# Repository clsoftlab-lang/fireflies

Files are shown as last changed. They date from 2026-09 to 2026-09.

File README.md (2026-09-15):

# Fireflies (반딧불이)

**English** · [한국어](README.ko.md)

> ### *A sky full of drifting light.*
> Hundreds of tiny helium **sky-jellyfish** — glowing bells with swaying tendrils — let go into
> the dusk air, blinking together in slow, self-organising rhythm, like jellyfish adrift in a
> night sea. Gentle art. Safe. Leave no trace.

Fireflies is an open-source night-sky art project. We release a cloud of thumbnail-size,
self-lit floaters and then **let the wind carry them**. There is no GPS, no steering, no
formation. Each unit only floats and blinks. The drifting *is* the art.

**Project lead:** CLSOFTLAB (씨엘소프트랩), Dr. Lee Il-guk (이일국 박사)
**Contributors:** LWJ (high-school student, Gyeonggi-do), LMJ (middle-school student, Gyeonggi-do),
and Claude (Anthropic's AI). Designed with Claude; **this is not an Anthropic product.**

> [!IMPORTANT]
> **The simulator is the show you can run today.** Open [`sim/`](sim/) in any browser and watch
> thousands of light-jellyfish drift and fall into sync — no hardware, no build step. The
> physical units are an honest reference design; real balloons that lift electronics are bigger
> than the 2 cm dream, and free flight needs permits. See **[Safety & airspace](#safety--airspace)**
> before any real flight.

---

## The one idea: we don't steer them, the wind does

This project began at a riverside at dusk. Clouds of tiny insects drift and swirl on the air,
and real fireflies blink in a rhythm that slowly falls into unison. Fireflies recreates that
feeling with light.

A single button *starts* the show — it releases the units and lights them. After that, **the wind
does the choreography** (principle F1 in the [design spec](docs/en/00-design-spec.md)). No position
holding, no collision avoidance, no drawing letters in the sky. This is the opposite of a
commercial drone light show, and it is what makes Fireflies simple, cheap, and small enough to be
genuinely thumbnail-sized. Drifting apart is not a failure — it is the whole point.

## Two forms: sky-jellyfish and firefly

The same floating, wind-drifting, self-blinking unit comes in two visual forms:

- **Sky-jellyfish (해파리) — the v1 form.** The helium balloon is the *bell*; from it hang 3–8
  feather-light **tendrils**, each carrying a line of micro-LEDs. In the air the tendrils sway and
  trail on the wind exactly like a jellyfish drifting on a current. The light runs **down each
  tendril, top to bottom, in a slow wave**, so the whole thing looks like it is gently pulsing and
  swimming.
- **Firefly — the simpler variant.** A single point of light that blinks: scattered sparks over a
  river.

The [simulator](sim/) draws both.

## How they blink together (no leader)

Each unit carries a tiny internal clock. Its "phase" ramps up smoothly and, when it reaches the top,
the unit flashes and resets. Whenever a unit *sees* a bright neighbour flash — with a little light
sensor — it nudges its own phase forward a touch. That is the only rule, and nobody is in charge.
Yet across a whole drifting swarm, random blinking slowly pulls itself into waves of unison. This is
a **pulse-coupled oscillator** (the Mirollo–Strogatz model), the same trick real fireflies use, and
light is the only channel — no radio, no coordinator. The [simulator](sim/) runs the identical model,
so what you watch on screen is what the hardware aims for.
[Read the friendly, illustrated-in-words explanation →](docs/en/05-synchrony-explained.md)

## A spark-like flash — with no spark

A steady micro-LED is too dim to see at dusk, which is exactly when a firefly show is magical. We
want the sharp, bright *pop* of an electric spark — so each unit makes a **capacitor-boosted LED
flash**: a small capacitor charges quietly, then dumps into the LED for a brief, intense burst, like
a camera flash. It is dark between flashes and snaps bright at the peak, staying visible far across a
dusk sky, and a touch of cool white/blue mixed into the amber can even mimic a spark's colour.

**We never put a real spark or any ignition source on a flying unit.** A free-drifting object can
land anywhere — dry grass, a rooftop, a crowd — and a spark is a fire risk (it is also a one-shot
click, not the gentle repeating blink of a firefly). The capacitor flash gives the crisp spark-like
look with no flame and no ignition, light enough for a micro-balloon. See
[design spec §5.1](docs/en/00-design-spec.md#51-brightness--a-spark-like-flash-without-a-spark).

## Try it now

The simulator **is** the landing experience — the full-scale dream, shareable by a link.

- **In this repo:** open [`sim/index.html`](sim/index.html) in any modern browser (no install, no build).
- **On the web:** <https://clsoftlab-lang.github.io/fireflies/sim/> *(published from `sim/` via GitHub Pages)*.

Play with the number of units, wind strength, blink period, coupling strength and colour, and watch
random flashes drift into slow unison.

## Repository map

```
docs/en, docs/ko   design spec, build guide, safety, leave-no-trace, synchrony
sim/               browser simulator (HTML/CSS/JS, no build) + tests  ← start here
hardware/          firefly/jellyfish unit + dispenser: OpenSCAD parts, BOM, wiring
firmware/          blink + sync firmware (unit) and dispenser controller
site/              optional project page (the simulator is the real landing page)
```

The [design spec](docs/en/00-design-spec.md) is the single source of truth. The `sim/`, `hardware/`
and `firmware/` folders are built by parallel work from that spec; if a folder is not populated in
your checkout yet, the simulator and docs still stand on their own.

## Build it

Order of work — try the simulator first, then build up:

1. **Run the [simulator](sim/)** to understand the drift-and-sync behaviour.
2. **Build one jellyfish (or firefly) unit:** a metallised-film or biodegradable-latex micro-balloon
   *(bell)*, a micro-LED with a capacitor-boosted flash, the smallest coin/film cell that stays
   inside the lift budget, a tiny ATtiny-class blink circuit, and an optional phototransistor for
   sync. For the jellyfish form, add 3–8 feather-light LED tendrils.
3. **Build the dispenser** — one 3D-printable desktop machine that fills a balloon with helium,
   **trims it to near-neutral buoyancy** on a tiny load cell, arms and light-tests the LED, and
   releases units one at a time on a start button (which is also an all-stop).
4. **Run an indoor / tethered show** — the default, legal-anywhere mode.

Full steps and commands: **[Build guide](docs/en/01-build-guide.md)** ·
parts and prices: **[Bill of materials](docs/en/02-bill-of-materials.md)** ([bom.csv](docs/bom.csv)).

> [!NOTE]
> **Honest about size.** A true 2 cm thumbnail unit that carries a micro-LED, a cell and a circuit
> *and* still floats does not exist with today's off-the-shelf parts. The **2 cm unit is
> simulator-only**; the reference *hardware* unit is the smallest we can actually build.
> **The buoyancy one-liner:** helium gives roughly **1 gram of lift per litre** it displaces
> (lift ≈ (air − helium density) × volume × *g*), so a 2 cm balloon (~4 mL) lifts only a few
> milligrams — far less than any real LED and cell. Bigger bell, more lift; trim it until it hangs.

## Safety & airspace

> [!WARNING]
> **Read [Safety & airspace](docs/en/03-safety-and-airspace.md) before any real flight.**
>
> - **Default mode is indoor or tethered** — each unit on a fine, retrievable line. This is the
>   fully-legal-anywhere way to run a show, and it is what the whole reference design is built around.
> - **Free wind-release is advanced and permit-required.** Free-floating lit objects are a hazard
>   to aircraft and are restricted in most countries. In Korea the **Aviation Safety Act**
>   (항공안전법) governs light shows, balloon releases and airborne devices — permission and
>   coordinates are required. Only open, low-altitude, permitted sites, coordinated with local
>   aviation authorities.
> - **Never fly near aircraft or airports, over crowds or roads, or in wildlife-sensitive areas**
>   without review.
> - **Helium is an asphyxiant** in enclosed spaces and cylinders are high-pressure — handle per the
>   hardware guide. Use the smallest safe battery; never release a damaged cell.

## Leave no trace

> [!IMPORTANT]
> **Read [Leave no trace](docs/en/04-leave-no-trace.md).** A firefly is not litter.
>
> - Prefer **tethered + recovered** operation, where nothing is lost.
> - Any free-release uses a **biodegradable envelope**, a **cellulose/paper LED carrier** and a
>   **recoverable or compostable** power source where possible.
> - **Released count must equal recovered/accounted count.** Log every unit and organise collection.
> - There is **no "release thousands and walk away" mode**, and there never will be.

## Contributors

- **Dr. Lee Il-guk (이일국 박사), CLSOFTLAB (씨엘소프트랩)** — project lead and design.
- **LWJ** — contributor (high-school student, Gyeonggi-do).
- **LMJ** — contributor (middle-school student, Gyeonggi-do).
- **Claude (Anthropic's AI)** — design collaborator.

New contributors are very welcome, **especially students and young makers.** See
[CONTRIBUTING.md](CONTRIBUTING.md) and the [Code of Conduct](CODE_OF_CONDUCT.md).

## Sister projects

- [Open Walking Safety Helmet](https://github.com/clsoftlab-lang/open-walking-safety-helmet)
- [RoboSoul humanoid](https://github.com/clsoftlab-lang/robosoul-humanoid)

## Licences

Open licences only:

- **Software** (`sim/`, `firmware/`, scripts, CI): Apache-2.0 — [`LICENSES/Apache-2.0.txt`](LICENSES/Apache-2.0.txt)
- **Hardware** (`hardware/`: OpenSCAD, STL, wiring): CERN-OHL-P-2.0 — [`LICENSES/CERN-OHL-P-2.0.txt`](LICENSES/CERN-OHL-P-2.0.txt)
- **Documentation** (`docs/`, READMEs, images): CC BY 4.0 — [`LICENSES/CC-BY-4.0.txt`](LICENSES/CC-BY-4.0.txt)

See [`NOTICE`](NOTICE) for which licence applies where, and [`LICENSE`](LICENSE) for the full text.

## Not an Anthropic product

Fireflies was designed with Claude, Anthropic's AI assistant. It is an independent open-source
project by CLSOFTLAB. It is **not** an Anthropic product and is not endorsed by Anthropic; there is
no affiliation, and no Anthropic or Claude branding is used.

## Why

Because a riverside at dusk, with the air full of small drifting lights blinking slowly into one
rhythm, is one of the quietest, most beautiful things there is — and everyone should be able to make
one, safely, and leave the river exactly as they found it.

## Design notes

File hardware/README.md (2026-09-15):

<!--
SPDX-License-Identifier: CERN-OHL-P-2.0
SPDX-FileCopyrightText: 2026 CLSOFTLAB / Dr. Lee Il-guk (이일국) and Fireflies contributors
-->
# Fireflies hardware — sky-jellyfish unit + dispenser machine

Reference hardware for the [design spec](../docs/en/00-design-spec.md). Two things:

1. the flying **sky-jellyfish (해파리)** unit — a helium micro-balloon *bell* with glowing
   *tendrils* (spec §3, §3.1), and
2. the desktop **dispenser machine** that fills a balloon to near-neutral buoyancy,
   arms + self-tests the LED payload, and releases units on a button (spec §4).

> **Read the safety and leave-no-trace sections of the spec first** (§6, §7). Free
> release of lit floating objects is airspace-restricted; the default modes are
> **indoor** or **tethered + recovered**. Nothing here is a drone, a formation, or a
> targeting system — the wind does the choreography and we do not steer anything.

Firmware for both lives in [`../firmware/`](../firmware/) (pure, host-tested Python +
ATtiny/Pico porting notes).

---

## 1. Bill of materials — sky-jellyfish unit

The unit is **mass-budget-critical**: every milligram below the bell eats into the
balloon's free lift (see §3). Choose the lightest option you can source.

### 1a. The bell (envelope) — two choices

| Option | What | Pros | Cons | Leave-no-trace |
|---|---|---|---|---|
| **Metallised film** ("foil") micro-bubble, ~13–20 cm | Mylar/nylon film balloon | Holds helium for **days**; low permeability; robust; self-sealing valve | **Not biodegradable**; must be recovered; conductive film near electronics | ❌ recover every unit — never free-release foil |
| **Biodegradable latex** micro-balloon, ~15–25 cm | Natural-rubber latex | Breaks down in the environment; non-conductive | Leaks helium in **hours**; shorter show; lift drops as it deflates | ✅ preferred for any permitted free-release, with full recovery logging |

**Rule (spec §7):** for any free-release, use the **latex** bell + a cellulose/paper
carrier + a recoverable/compostable cell, and a released-count == recovered-count log.
Foil is for **tethered indoor** shows where every unit comes back.

### 1b. Payload

| Part | Choice | Typical mass | Notes |
|---|---|---|---|
| Amber LED (base glow) | 0402 or 0603, ~590 nm | ~2 mg (0402) / ~4 mg (0603) | firefly colour (spec §3) |
| Cool-white LED(s) (flash) | a few 0402 | ~2 mg each | mixed into amber for the spark tint (§5.1) |
| Boost capacitor | 100 µF class, small tantalum/ceramic | ~30–200 mg | charges quietly, dumps into the LED (§5.1) |
| MCU | ATtiny85 / ATtiny1616 (SOIC/QFN or bare die) | ~10 mg (die) / ~70 mg (SOIC) | firmware sync; **OR** a discrete analog blinker (no sync) |
| Sync sensor | 1 × phototransistor (small SMD) | ~5 mg | sees neighbours' flashes (§5) — optional |
| Power | smallest cell that fits the budget | ~50–150 mg (thin-film) / ~600 mg (CR1025 coin) | thin-film/printed cell is lightest; coin cell for longer runtime |
| Tendrils | 3–8 strands: conductive thread **or** micro-film ribbon + micro-LEDs | ~5–20 mg per strand | must hang and sway softly, not stiff (§3.1) |
| Payload carrier / tendril spreader | **die-cut cellulose/paper** (free-release) **or** the printed light ring (`jellyfish_carrier`) | ~20–50 mg (paper) / ~200–400 mg (printed PLA) | the printed ring is only viable on larger balloons — see mass budget |

An **analog-only firefly** (single amber LED + cell + relaxation-oscillator blinker +
boost-cap flash, no MCU/phototransistor) is the cheapest, lightest build. It just
blinks; it does not synchronise.

---

## 2. Bill of materials — dispenser machine

| Part | Choice | Notes |
|---|---|---|
| Controller | Raspberry Pi Pico **or** Arduino Nano | runs the fill/trim/test/release firmware |
| Helium valve | 9 g micro-servo pinch-valve **or** small solenoid, on a low-pressure silicone line | meters helium (spec §4 stage 2); **downstream of a regulator** — never the cylinder valve |
| Buoyancy sensor | bar **load cell** (≈100 g range) + **HX711** 24-bit amp | resolves sub-0.1 g free lift for near-neutral trim (§F2) |
| LED self-test | photodiode (5 mm) in the printed hood | confirms the unit blinked before release (§4 stage 3) |
| Release | micro-servo gate + printed magazine + gate | one unit at a time (§4 stages 1, 4) |
| Frame | 3D-printed parts below | 220 × 220 × 250 mm bed |
| Fasteners | M3 screws/heat-inserts, servo horns | mounting grid on the frame base |
| Helium | party-grade He, **regulated**, in a ventilated space | asphyxiant in enclosed spaces; cylinders high-pressure (§6) |

### 3D-printed parts (`openscad/`)

| Part file | STL | What it is |
|---|---|---|
| `dispenser_frame.scad` | `stl/dispenser_frame.stl` | base plate + upright back panel + gusset ribs; mounting grid |
| `balloon_magazine.scad` | `stl/balloon_magazine.stl` | slotted magazine feeding flat empty envelopes one at a time |
| `release_gate.scad` | `stl/release_gate.stl` | servo gate housing + slider that frees one unit |
| `servo_valve_mount.scad` | `stl/servo_valve_mount.stl` | holds the micro-servo + anvil for the helium pinch-valve |
| `load_cell_mount.scad` | `stl/load_cell_mount.stl` | fixed clamp for the bar load cell + separate moving tether platform |
| `led_test_jig.scad` | `stl/led_test_jig.stl` | dark hood + photodiode bore for the LED self-test |
| `electronics_tray.scad` | `stl/electronics_tray.stl` | tray with standoffs for the Pico + HX711 |
| `jellyfish_carrier.scad` | `stl/jellyfish_carrier.stl` | **the only flying printed part**: a feather-light tendril-spreader ring |
| `lib/common.scad` | — | shared helpers (rounded boxes, holes, bosses, bed-fit check) |

Wiring diagrams: [`wiring/jellyfish_unit.svg`](wiring/jellyfish_unit.svg),
[`wiring/dispenser.svg`](wiring/dispenser.svg).

---

## 3. Buoyancy physics — and the honest size limit

A balloon floats because the helium inside displaces heavier air. The **gross lift**
is the weight of air displaced minus the weight of the helium:

```
lift  ≈  (ρ_air − ρ_He) × Volume
ρ_air ≈ 1.225 g/L,  ρ_He ≈ 0.166 g/L   (sea level, ~15 °C)
⇒  lift ≈ 1.06 g of lift per litre of helium
```

So a payload of **X grams needs ≈ X / 1.06 litres** of helium — i.e. a balloon of at
least that volume. For a sphere of diameter *d*, `V = (4/3)·π·(d/2)³`. Worked examples
(these are the numbers the firmware's `buoyancy.helium_litres_for_lift()` uses):

| Sphere Ø | Helium volume | Gross lift |
|---:|---:|---:|
| **20 cm** | 4.19 L | **≈ 4.44 g** (4.4 g) |
| 18 cm | 3.05 L | ≈ 3.24 g |
| 15 cm | 1.77 L | ≈ 1.87 g |
| **6 cm** | 0.113 L | **≈ 0.12 g** (120 mg) |
| **2 cm** | 0.0042 L | **≈ 0.0044 g** (4.4 mg) |

**Net (free) lift = gross lift − envelope film mass − payload mass**, and near-neutral
trim means free lift is a hair above zero (the dispenser targets ~+0.2 g so the unit
hangs and drifts, not shoots up).

### Mass budget for the unit

| Build | Payload mass (typical) | Envelope film | Balloon needed (gross lift ≥ film + payload + ~0.2 g trim) |
|---|---:|---:|---|
| **Analog firefly** (1 amber LED, thin-film cell, analog blinker, paper carrier) | ~0.15–0.4 g | ~1.5 g (foil) / ~1.0 g (latex) | ~15–18 cm (≈1.9–3.2 g gross) |
| **Full sky-jellyfish** (MCU + phototransistor + boost cap + cool-white + 6 tendrils + printed/paper carrier) | ~0.7–2.0 g | ~1.5 g | ~18–22 cm (≈3.2–5.5 g gross) |

Note how the **printed carrier ring** (~0.2–0.4 g PLA) alone is 2–3× the *entire* free
lift of a 6 cm balloon (0.12 g). That is why free-release units use a die-cut
cellulose/paper carrier (~20–50 mg) instead, and why the bell must be 15 cm+.

### The honest limit (spec §3, §3.1)

A true **2 cm thumbnail** unit lifts only **~4.4 mg** — far less than a single coin
cell (hundreds of mg) or even a bare LED + die. **A 2 cm self-lit floater does not
exist with today's off-the-shelf parts.** The 2 cm dream is **simulator-only**; the
smallest *buildable* reference unit is the 15–22 cm sky-jellyfish above. We document
both honestly rather than pretend the thumbnail flies.

---

## 4. Build & verify

Render every part to STL + a preview PNG, then check bed-fit:

```powershell
# from hardware/
pwsh scripts/render_all.ps1        # or: bash scripts/render_all.sh
python scripts/check_stl.py        # non-empty + fits 220 x 220 x 250 mm
```

`render_all` writes STLs to `stl/` and PNGs to `renders/`. `check_stl.py` reports each
part's triangle count and bounding box and fails if anything is empty or too big. All
eight parts currently pass and fit the bed.

Firmware tests (from `../firmware/`): `python -m pytest tests -q`.

---

## 5. Safety notes (see spec §6, §7)

- **Helium** is an asphyxiant in enclosed spaces; cylinders are high-pressure. The
  servo valve only meters a **regulated low-pressure** line — the firmware never
  touches the cylinder regulator. Work in a ventilated space.
- **No ignition source ever flies.** The "spark-like" look is a capacitor-boosted LED
  flash (§5.1), never a real spark. A free-drifting object can land anywhere.
- **Default modes are indoor or tethered + recovered.** Free release is airspace-
  restricted (in Korea, the Aviation Safety Act) and is "advanced / permit required".
- **Leave no trace:** latex bell + cellulose carrier + recoverable cell for any free
  release; log released == recovered.
- **Batteries:** smallest safe cell; never release a damaged cell.

Licence: hardware **CERN-OHL-P-2.0**. See [`../LICENSES/`](../LICENSES/).

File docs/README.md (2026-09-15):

# Documentation · 문서

> Part of Fireflies · CC BY 4.0 · © 2026 CLSOFTLAB, Dr. Lee Il-guk
> 반딧불이 프로젝트의 일부 · CC BY 4.0 · © 2026 씨엘소프트랩, 이일국 박사

*A sky full of drifting light.* · *하늘 가득 흩어져 떠다니는 빛.*

The design specification is the single source of truth. When a guide and the spec disagree, the spec
wins — please [open an issue](https://github.com/clsoftlab-lang/fireflies/issues).

설계서가 유일한 기준 문서입니다. 가이드와 설계서가 다르면 설계서를 따르고, 이슈로 알려 주십시오.

## Where to start · 어디서 시작할까요

- **I just want to see it:** open the [simulator](../sim/) — it is the landing experience.
  **그냥 보고 싶어요:** [시뮬레이터](../sim/)를 여세요. 첫 화면 경험입니다.
- **I want to build one:** [Build guide](en/01-build-guide.md) →
  [Bill of materials](en/02-bill-of-materials.md) → [Safety & airspace](en/03-safety-and-airspace.md) →
  [Leave no trace](en/04-leave-no-trace.md).
  **직접 만들려고 합니다:** [제작 가이드](en/01-build-guide.md) →
  [부품 목록](en/02-bill-of-materials.md) → [안전과 항공](en/03-safety-and-airspace.md) →
  [흔적을 남기지 않기](en/04-leave-no-trace.md).
- **I want to understand the sync:** [Synchrony explained](en/05-synchrony-explained.md).
  **동기화 원리가 궁금합니다:** [동기화 설명](en/05-synchrony-explained.md).
- **I want to contribute:** [CONTRIBUTING.md](../CONTRIBUTING.md).
  **기여하고 싶습니다:** [CONTRIBUTING.md](../CONTRIBUTING.md).

## All documents · 전체 문서

| # | English | 한국어 | For |
|---|---|---|---|
| 00 | [Design specification](en/00-design-spec.md) | [설계서](ko/00-설계서.md) | Everyone building or changing anything |
| 01 | [Build guide](en/01-build-guide.md) | *번역 환영* | Builders |
| 02 | [Bill of materials](en/02-bill-of-materials.md) · [bom.csv](bom.csv) | *번역 환영* | Builders |
| 03 | [Safety & airspace](en/03-safety-and-airspace.md) | *번역 환영* | Everyone, before any real flight |
| 04 | [Leave no trace](en/04-leave-no-trace.md) | *번역 환영* | Everyone |
| 05 | [Synchrony explained](en/05-synchrony-explained.md) | *번역 환영* | Students, curious readers |

The Korean **[설계서 (design spec)](ko/00-설계서.md)** is a complete translation and is the Korean
single source of truth. Korean translations of guides 01–05 are very welcome — see
[Other languages](#other-languages--다른-언어).

## Project files · 프로젝트 파일

- [Project README](../README.md) · [한국어 README](../README.ko.md)
- [Contributing](../CONTRIBUTING.md) · [Code of Conduct](../CODE_OF_CONDUCT.md) ·
  [Governance](../GOVERNANCE.md) · [Security](../SECURITY.md)
- [Licence notice](../NOTICE) · [Licence](../LICENSE)

## Sister projects · 자매 프로젝트

- [Open Walking Safety Helmet](https://github.com/clsoftlab-lang/open-walking-safety-helmet)
- [RoboSoul humanoid](https://github.com/clsoftlab-lang/robosoul-humanoid)

## Other languages · 다른 언어

Documentation in other languages is welcome under `docs/<lang>/` with local file names (for example
`docs/ko/01-제작가이드.md`), following the pattern of the sister projects. See
[CONTRIBUTING.md](../CONTRIBUTING.md).

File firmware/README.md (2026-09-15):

<!--
SPDX-License-Identifier: Apache-2.0
SPDX-FileCopyrightText: 2026 CLSOFTLAB / Dr. Lee Il-guk (이일국) and Fireflies contributors
-->
# Fireflies firmware

Pure, host-testable logic for the two devices in the [design spec](../docs/en/00-design-spec.md):

- **`firefly_unit/`** — the flying sky-jellyfish (해파리) behaviour.
- **`dispenser/`** — the desktop machine that fills, trims, tests and releases units.

Everything here is **plain Python with no hardware dependency**. The wall clock and
all hardware (photosensor, LEDs, load cell, helium valve) are *injected* interfaces,
so the exact same logic runs under `pytest` on a laptop and, ported, on an
ATtiny/Pico. Nothing in this folder needs to be cross-compiled to be tested.

## Layout

```
firefly_unit/
  sync.py       pulse-coupled oscillator — synchronised blinking, no leader (spec §5)
  tendril.py    travelling-wave light down the jellyfish tendrils (spec §3.1)
  flash.py      capacitor-boosted spark-like flash profile (spec §5.1)
  led_mixer.py  amber base + cool-white spark tint (spec §3, §5.1)
  unit.py       ties them together via an injected clock + UnitHAL
  embedded/     pin-mapping notes for real ATtiny / Pico targets (MicroPython + C)
dispenser/
  buoyancy.py   fill-to-near-neutral-trim control loop (spec §4, F2)
  sequence.py   per-unit state machine: load → fill → arm+LED test → release (spec §4)
  controller.py start / all-stop, releases one at a time on a gentle cadence (spec §4)
tests/          pytest — all green
```

## Run the tests

```powershell
cd firmware
python -m pytest tests -q
```

34 tests cover: sync convergence to synchrony, tendril wave bounds + downward
travel, flash peak/decay profile, colour mixing, buoyancy loop reaching trim and
stopping without overshoot, the sequence never releasing a dead-LED or
wrongly-buoyant unit, and all-stop halting releases.

## Design notes

- **No spark, ever, on a flying unit.** The "spark-like" look is a *capacitor-boosted
  LED flash* (`flash.py`), never an ignition source — see spec §5.1. A free-drifting
  object can land anywhere; a real spark is a fire risk.
- **Light is the only sync channel** (`sync.py`): no radio, no coordinator. Units
  nudge their blink toward the neighbours their phototransistor can see.
- **Safety guards live in the dispenser, not the sky:** `sequence.py` refuses to
  release any unit that failed its LED self-test or is not at near-neutral trim.

## Porting to hardware

The pure logic is target-agnostic. See [`firefly_unit/embedded/README.md`](firefly_unit/embedded/README.md)
for the ATtiny/Pico pin maps and how the injected interfaces (`UnitHAL`, `LoadCell`,
`HeliumValve`) map to real ADC/PWM/servo/HX711 calls. Embedded builds are **not**
verified here — only the pure logic is.

Licence: Apache-2.0.

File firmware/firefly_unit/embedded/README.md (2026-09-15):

<!--
SPDX-License-Identifier: Apache-2.0
SPDX-FileCopyrightText: 2026 CLSOFTLAB / Dr. Lee Il-guk (이일국) and Fireflies contributors
-->
# Embedded targets — pin mapping (unit + dispenser)

The Python in `firefly_unit/` and `dispenser/` is the **reference behaviour**. On real
hardware you re-implement the small `UnitHAL` / `LoadCell` / `HeliumValve` interfaces
against the chip's peripherals; the maths (sync, tendril wave, flash envelope,
buoyancy loop, sequence) is copied over unchanged. **Not compiled or flashed here** —
this is a wiring/porting note only.

## A. Flying unit — ATtiny85 or ATtiny1616 (analog blinker is a no-MCU alternative)

The unit is mass-budget-critical (every milligram, see `hardware/README.md`), so the
MCU is the smallest that does the job.

| Pure interface (`unit.UnitHAL`) | Signal | ATtiny1616 pin | Notes |
|---|---|---|---|
| `read_photosensor()` | phototransistor → ADC | PA4 (ADC0/AIN4) | sees neighbour flashes; feeds `sync.py` |
| `set_bell_led(rgb)` amber ch | amber LED PWM | PB0 (TCA0 WO0) | warm ~590 nm base glow |
| `set_bell_led(rgb)` white ch | cool-white LED PWM | PB1 (TCA0 WO1) | spark tint at flash peak |
| flash cap gate | MOSFET gate → cap→LED | PA5 (digital out) | dumps the boost capacitor (§5.1) |
| `set_tendril_leds(frame)` | tendril LED string | PA1 (SPI/1-wire) | e.g. tiny addressable string, or PWM banks |

Timekeeping: the injected `clock()` becomes the RTC / `millis()` equivalent
(TCB in periodic mode). Call `FireflyUnit.step(now)` each tick (~50–100 Hz is ample).

**Analog-only variant (no firmware):** replace the MCU with a relaxation oscillator
(e.g. a small timer IC or transistor astable) driving the amber LED, plus the
capacitor-boost stage for the flash. It just blinks — no light-based synchrony. This
is the cheapest, lightest build; `sync.py` only matters if you fit the MCU +
phototransistor.

### MicroPython sketch (Pico-class unit, if used instead of ATtiny)

```python
from machine import ADC, PWM, Pin
from time import ticks_us, ticks_diff
from firefly_unit.unit import FireflyUnit, UnitConfig

class PicoHAL:
    def __init__(self):
        self.photo = ADC(26)
        self.amber = PWM(Pin(0)); self.white = PWM(Pin(1))
        self.amber.freq(1000); self.white.freq(1000)
    def read_photosensor(self):
        return self.photo.read_u16() / 65535
    def set_bell_led(self, rgb):
        r, g, b = rgb
        self.amber.duty_u16(int(min(1.0, (r+g)/2) * 65535))
        self.white.duty_u16(int(b * 65535))
    def set_tendril_leds(self, frame):
        ...  # drive the addressable tendril string

hal = PicoHAL()
t0 = ticks_us()
unit = FireflyUnit(hal, clock=lambda: ticks_diff(ticks_us(), t0) / 1e6, config=UnitConfig())
while True:
    unit.step()
```

## B. Dispenser — Raspberry Pi Pico (or Arduino Nano)

| Pure interface | Signal | Pico pin | Notes |
|---|---|---|---|
| `LoadCell.read_lift_grams()` | HX711 DOUT / SCK | GP14 / GP15 | balloon free-lift on the load cell (§4) |
| `HeliumValve.set_open_fraction()` | micro-servo PWM **or** solenoid | GP16 (PWM) / GP17 (gate) | servo pinch-valve or solenoid on the He line |
| LED self-test photodiode | photodiode → ADC | GP26 (ADC0) | confirms the unit blinked (§4 stage 3) |
| start button | button → GPIO in | GP2 (pull-up) | `Dispenser.start()` |
| all-stop button | button → GPIO in | GP3 (pull-up) | `Dispenser.all_stop()` |
| release gate servo | servo PWM | GP18 | opens the gate to release one unit |
| magazine advance | servo/stepper | GP19 | loads the next envelope |

Loop: read HX711 → `BuoyancyController.step()` sets the valve; run `Dispenser.tick(now)`
each control period; poll the two buttons into `start()` / `all_stop()`. HX711,
servo and button drivers are the only board-specific code; all decision logic is the
tested Python ported to MicroPython/C.

**Helium handling** (spec §6): helium is an asphyxiant in enclosed spaces and cylinders
are high-pressure — the valve only *meters* from a regulated low-pressure line; the
firmware never controls the cylinder regulator.

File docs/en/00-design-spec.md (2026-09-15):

# Fireflies (반딧불이) — Design Specification (v0.1)

> **Status:** Concept + reference design v0.1 · **Single source of truth.** The browser simulator,
> the dispenser hardware, the firefly unit and all guides follow this document. Change it first,
> then the implementations.

- Project: **Fireflies (반딧불이)** — an open, gentle night-sky art installation: hundreds of tiny,
  ultra-light LED **sky-jellyfish** (해파리) — helium micro-balloons with glowing tendrils — that are
  released into the air and **left to drift on the wind**, tendrils swaying and light flowing down them,
  blinking in slow, self-organising synchrony, like jellyfish adrift in a night sea (§3.1).
  The v1 form is the **sky-jellyfish**; the plain single-point "firefly" is a simpler variant.
- Project lead: **CLSOFTLAB (씨엘소프트랩), Dr. Lee Il-guk (이일국 박사)**
- Contributors: **LWJ** (high school student, Gyeonggi-do), **LMJ** (middle school student, Gyeonggi-do)
- Designed with Claude (Anthropic's AI). Not an Anthropic product.
- Licences: software Apache-2.0 · hardware CERN-OHL-P-2.0 · documentation CC BY 4.0.

---

## 1. What this is — and what it is not

The idea began at a riverside: at dusk, clouds of tiny insects drift and swirl, pushed by the air, and
real fireflies blink in a rhythm that slowly falls into sync. Fireflies recreates that feeling with
hundreds of thumbnail-size lights.

**The central design choice: we do not control where they go.** A single button "starts" the show —
it releases the fireflies and lights them — and after that **the wind carries them**. There is no GPS,
no position holding, no formation, no steering. Drifting apart is not a failure; it *is* the art.

This makes Fireflies fundamentally different from a commercial drone light show (which precisely
positions each drone to draw letters and logos). It also makes it far simpler, far cheaper, and small
enough to be genuinely thumbnail-sized.

| # | Principle | Consequence |
|---|---|---|
| F1 | **Let the wind do the choreography** | No GPS, no position control, no collision avoidance. Each unit only floats and blinks. |
| F2 | **Barely-there lift** | Each firefly is a helium micro-balloon trimmed to near-neutral buoyancy, so it hangs and drifts rather than shooting up. |
| F3 | **Blink in synchrony, with no leader** | Each unit nudges its blink toward the neighbours it can see (a pulse-coupled oscillator, like real fireflies). Order emerges; nobody is in charge. |
| F4 | **Leave no trace** | Every part that flies is chosen to come down safely and break down in nature, plus a recovery plan. This is a firefly, not litter. See §7. |
| F5 | **Gentle and legal** | Low altitude, tethered or fenced options, clear airspace rules, no hazard to aircraft, people, or wildlife. See §6. |
| F6 | **Anyone can make it** | Globally available parts; the "machine" is one 3D-printable dispenser; the simulator runs in any browser. |
| F7 | **Simulate first, at any scale** | The browser simulator has no size or count limit: thumbnail fireflies, thousands of them, drifting and syncing — the dream, viewable by a link. Reality is documented honestly alongside. |
| F8 | **Open licences** | Apache-2.0 / MIT / BSD / CC-BY only. |

---

## 2. System overview

```
   ┌──────────────── DISPENSER (the "machine") ────────────────┐        the wind
   │  helium micro-fill  →  buoyancy trim  →  LED arm & test    │           ↓
   │  →  release one firefly at a time     ← start button       │   ✦   ✧      ✦
   │  (§4)                                                       │      ✧   ✦  ✧     ✦
   └───────────────────────────┬────────────────────────────────┘   ✦      ✧      ✦
                               │ releases                            drifting + blinking
                               ▼                                     in slow synchrony (§5)
                    ┌──── FIREFLY UNIT (§3) ────┐
                    │ micro-balloon (He)         │
                    │ + micro-LED + coin cell    │
                    │ + tiny blink circuit       │
                    │ near-neutral buoyancy      │
                    └────────────────────────────┘

   BROWSER SIMULATOR (§8): thousands of fireflies released, drifting on a wind field,
   blinking into sync — no hardware needed, shareable by link.
```

Two tracks, both open-sourced:
- **Simulator track** (primary): a browser world where the dream runs at full scale today.
- **Hardware track** (reference design): the firefly unit and the dispenser machine, documented honestly
  including where physics limits real size and flight time.

---

## 3. Firefly unit (reference design, hardware track)

The goal: the smallest, lightest self-lit floater that drifts on indoor/very-light-wind air.

| Part | Choice | Notes |
|---|---|---|
| Envelope | Metallised film ("foil balloon") micro-bubble, ~5–8 cm, OR a biodegradable latex micro-balloon | Foil holds helium longer; latex breaks down better (§7). Thumbnail-size (2 cm) is a **simulator-only** dream today — real balloons that lift any electronics are bigger; documented honestly. |
| Lift gas | Helium, trimmed to **near-neutral buoyancy** | Fill until it neither rises fast nor sinks; it should hover and drift. Trim is the key skill (§4). |
| Light | 1 × micro-LED, warm amber base + a **bright capacitor-boosted flash** | Amber ~590 nm matches fireflies; the flash gives a sharp, spark-like "pop" that is visible at dusk (see §5.1). |
| Power | Smallest coin/film cell that floats within the buoyancy budget | Runtime is minutes to a couple of hours depending on balloon size and blink duty. |
| Blink circuit | Tiny microcontroller (ATtiny-class) OR a discrete analog blinker | Firmware option enables synchrony (§5) via a light sensor; the analog option just blinks. |
| Sync sensor (optional) | 1 × phototransistor | Sees neighbours' flashes to fall into rhythm. |
| Mass budget | Everything below the balloon's free lift | The lighter the payload, the smaller the balloon can be. Minimise every milligram. |

### 3.1 Two forms: firefly and sky-jellyfish

The same floating, wind-drifting, self-blinking unit comes in two visual forms:

- **Firefly form:** a single point of light that blinks — scattered sparks over a river.
- **Sky-jellyfish form (해파리):** the helium balloon is the *bell*, and from it hang several very light,
  glowing **tendrils** — thin conductive thread or micro-film ribbons with a line of micro-LEDs along
  each. In the air, the tendrils sway and trail on the wind exactly like a jellyfish drifting on a
  current — which is the same "let the wind carry it" idea (F1) made visible. Design of the tendrils:
  - **Bell:** the helium micro-balloon provides all the lift; keep the tendrils feather-light so buoyancy
    is barely affected (every milligram of tendril must stay inside the free-lift budget).
  - **Tendrils:** 3–8 strands, each with a few micro-LEDs; the strands must be light enough to hang and
    sway softly, not stiff.
  - **Flowing light:** run the light **down the tendril top→bottom** in a slow wave, so it looks like a
    jellyfish pulsing and swimming (many real jellyfish glow in travelling waves).
  - **Spark flash on the bell:** an occasional capacitor-boosted flash (§5.1) on the bell, over the gentle
    flowing tendrils, gives the crisp "pop" without any ignition source.

The simulator renders both forms; sky-jellyfish are drawn as a bell plus trailing, swaying, light-flowing
tendrils in the wind field.

**Honest limit:** a true 2 cm thumbnail unit that carries even a micro-LED, a cell and a circuit and
still floats does not exist with today's off-the-shelf parts. The reference *hardware* unit is the
smallest we can actually build (documented in `hardware/`); the *simulator* renders the 2 cm dream.

---

## 4. The dispenser machine

One 3D-printable desktop machine that turns raw balloons + a helium source into finished, glowing,
neutrally-trimmed fireflies and releases them on a button.

Stages:
1. **Load** an empty envelope from a magazine.
2. **Fill** with helium to a target free-lift, measured on a tiny load cell / balance so buoyancy is
   **trimmed near neutral** (the make-or-break step behind F2). Firmware closes the valve at target.
3. **Attach & arm** the LED payload; run a **light self-test** (blink once) so no dead unit is released.
4. **Release** one firefly at a time, or a gentle rhythm of them, on the operator's start signal.
5. **Start button / handheld remote**: the *only* live control — "begin releasing". Also an **all-stop**
   (stop releasing) and a documented plan for bringing tethered units down.

Reference build: Raspberry Pi Pico or Arduino-class controller, a micro servo/solenoid valve on the
helium line, a load cell + HX711-class amp for buoyancy, an LED-test photodiode, 3D-printed frame,
magazine and release gate. Full BOM and wiring in `hardware/`.

---

## 5. Synchronised blinking (the heart of it)

Real fireflies with no leader still flash in unison. Each firefly is modelled as a **pulse-coupled
oscillator**: it has an internal phase that ramps to a threshold, flashes, and resets; when it *sees*
a neighbour flash, it nudges its own phase forward a little. Across a swarm, this converges to
synchrony (Mirollo–Strogatz). We implement the same rule:

- Each unit ramps a phase 0→1 over a period T (≈ 1–2 s), flashes at 1, resets.
- On seeing a bright neighbour flash (phototransistor), advance phase by a small coupling ε.
- Result: fireflies that start random slowly blink together — with drift and wind making the pattern
  never quite the same. No radio, no coordinator; light is the only channel.

The **simulator** implements the identical model so what you see on screen is what the hardware aims for.

### 5.1 Brightness — a spark-like flash, without a spark

A single steady micro-LED is too dim to see at dusk, which is exactly when a firefly show is magical.
We want the sharp, bright "pop" of an electric spark — but we **never put a real spark or any ignition
source on a flying unit.** A free-drifting object can land anywhere (dry grass, a crowd, a rooftop), and
a spark is a fire risk; it is also a one-shot "click", not the gentle repeating blink of a firefly.

Instead, each firefly makes a **capacitor-boosted LED flash**: a small capacitor charges quietly, then
dumps into the LED for a brief, intense burst — like a camera flash or a bike tail-light strobe. It is
dark between flashes and snaps bright at the peak, giving the crisp spark-like "pop" and staying visible
far across a dusk sky. A touch of **cool white / blue** mixed into the amber can even mimic the colour of
an electric spark. No flame, no ignition, light enough for the micro-balloon. Peak brightness, flash
duration and colour are firmware parameters; the simulator renders the same sharp flash profile.

---

## 6. Safety and airspace (must-read before any real flight)

- **Aircraft safety first.** Free-floating lit objects near airports or in controlled airspace are a
  hazard and are restricted in most countries (in Korea, the Aviation Safety Act governs light shows,
  balloon releases and any airborne device; permission and coordinates are required). The default,
  fully-legal-anywhere mode is **indoor** or **tethered** (each firefly on a fine line, retrievable).
- **Free release** (true wind drift) is only for open, low-altitude, permitted sites, coordinated with
  local aviation authorities — documented as "advanced / permit required", never the default.
- No flight over crowds, roads, or wildlife-sensitive areas without review.
- Helium is an asphyxiant in enclosed spaces and cylinders are high-pressure — handling rules in `hardware/`.
- Batteries: use the smallest safe cell; never release damaged cells.

## 7. Leave no trace (environmental design)

- Prefer **tethered + recovered** operation (nothing is lost).
- For any free-release: use a **biodegradable envelope**, a **cellulose/paper LED carrier**, and a
  **recoverable or compostable** power source where possible; log how many are released and organise
  collection afterwards. A released count must equal a recovered/accounted count.
- The project will not publish a "release thousands and walk away" mode. Litter is the opposite of a firefly.

---

## 8. Browser simulator (primary deliverable)

A single-page web app (no build step, no external services) that shows the dream at full scale:
- A **wind field** (gentle, time-varying) drifts thousands of fireflies; they spread, swirl and never
  repeat — the riverside feeling.
- Each firefly runs the **pulse-coupled sync** model (§5); the audience watches random blinking fall
  into slow waves of unison.
- A **dispenser** at the bottom releases fireflies over time on a "start" button, matching the hardware story.
- Controls: number of fireflies, wind strength, blink period, coupling strength, colour; pause; a
  "leave no trace" note; accessible (keyboard, reduced-motion, high-contrast), responsive, light/dark.
- Runs at thousands of units on a normal laptop; degrades gracefully on phones.

## 9. Repository layout

```
docs/en, docs/ko          design spec, build guide, safety, environment
sim/                      browser simulator (HTML/CSS/JS, no build), tests
hardware/                 firefly unit + dispenser: OpenSCAD parts, BOM, wiring, firmware
firmware/                 blink + sync firmware (unit) and dispenser controller
site/                     project page (optional)
```

## 10. Phases

| Phase | Scope |
|---|---|
| P0 | Browser simulator: wind drift + pulse-coupled sync at thousands of units |
| P1 | One firefly unit on the bench: blink + sync between 2–5 units by light |
| P2 | Dispenser machine: helium fill + buoyancy trim + LED test + release, indoor/tethered |
| P3 | Tethered indoor show (retrievable), 10–50 units |
| P4 | Free release — only with permits, biodegradable units, full recovery (advanced) |

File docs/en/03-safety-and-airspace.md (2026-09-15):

# 03 · Safety & airspace

> Part of Fireflies · CC BY 4.0 · © 2026 CLSOFTLAB, Dr. Lee Il-guk

> [!WARNING]
> **Read this in full before any real flight.** Fireflies is gentle art, but anything that floats
> and lights up shares the sky with aircraft, people and wildlife. The default, legal-anywhere mode
> is **indoor or tethered**. Free wind-release is **advanced and permit-required** — never the
> default. This guide expands [design spec §6](00-design-spec.md#6-safety-and-airspace-must-read-before-any-real-flight);
> the spec wins if they disagree.

This document is general guidance, **not legal advice**. Laws differ by country and change over
time. You are responsible for checking and following the rules where you fly, and for getting any
permits before you fly.

## Contents

1. [The two modes](#1-the-two-modes)
2. [Aircraft & airspace](#2-aircraft--airspace)
3. [Korea: Aviation Safety Act](#3-korea-aviation-safety-act)
4. [Altitude, crowds & wildlife](#4-altitude-crowds--wildlife)
5. [Helium handling](#5-helium-handling)
6. [Battery safety](#6-battery-safety)
7. [Pre-flight checklist](#7-pre-flight-checklist)

---

## 1. The two modes

| Mode | What it is | Legality | When to use |
|---|---|---|---|
| **Indoor / tethered** *(default)* | Indoors, or each unit on a fine, retrievable line outdoors in still air | Legal-anywhere with normal venue permission | Almost always. The whole reference design targets this. |
| **Free wind-release** *(advanced)* | True wind drift, nothing tethered | **Permit required**; restricted or banned in many places | Only open, low-altitude, permitted sites, coordinated with aviation authorities, biodegradable units, full recovery |

If you are not sure which mode you are in, you are in free-release, and you need a permit.

## 2. Aircraft & airspace

- **Aircraft safety comes first, always.** Free-floating lit objects near airports or in controlled
  airspace are a genuine hazard to aircraft and are restricted in most countries.
- **Never fly near airports, heliports, or in controlled airspace.** Keep clear of approach and
  departure paths.
- Free-floating balloons cannot see or avoid anything (that is the point of principle F1 — the wind
  steers, not us), so the only safe free-release is one that authorities have reviewed for the exact
  place, time, altitude and recovery plan.
- Tethered and indoor operation avoids airspace entirely, which is why it is the default.

## 3. Korea: Aviation Safety Act

In Korea, the **Aviation Safety Act (항공안전법)** and its subordinate rules govern light shows,
balloon releases and airborne devices. In practice this means:

- **Permission and coordinates are required** for outdoor free-release or any airborne light show.
  Apply to the relevant aviation authority with the exact location, date/time window, maximum
  altitude, number of units and a recovery plan.
- **Airport / no-fly zones:** releases near airports and within controlled or restricted airspace
  are prohibited without specific clearance. Check the current zones before planning.
- **Altitude and notice:** stay within any altitude limit the authority sets, and give the required
  notice period.
- Rules change; always confirm the **current** requirements with the authority before you fly. When
  in doubt, run the show **indoor or tethered**, which does not require an airspace permit.

Other countries have their own equivalents (for example national civil aviation authority rules on
free balloons and outdoor light displays). The same principle holds everywhere: **free-release needs
a permit; tethered/indoor does not.**

## 4. Altitude, crowds & wildlife

- **Keep altitude low** — the art is a drifting dusk glow, not a high-altitude flight. Lower is
  safer for aircraft and for recovery.
- **No flight over crowds or roads** without review: a unit can come down anywhere, and a startled
  crowd or a distracted driver is a hazard even from a harmless object.
- **Protect wildlife.** Avoid wildlife-sensitive areas, nesting seasons and water bodies where units
  could be mistaken for food or entangle animals. Biodegradable materials and full recovery (see
  [04 · Leave no trace](04-leave-no-trace.md)) are part of this.
- **Weather:** do not release in gusty or unsettled wind, near storms, or when you cannot keep the
  drift within your permitted, recoverable area.

## 5. Helium handling

Helium is not flammable, but it has two real hazards:

- **Asphyxiant in enclosed spaces.** Helium displaces air. In a small or poorly-ventilated room it
  can lower oxygen to dangerous levels. **Fill and run indoors only with good ventilation.** Never
  breathe helium.
- **High-pressure cylinders.** A helium cylinder stores gas under high pressure and can become a
  dangerous projectile if the valve is damaged.
  - Secure the cylinder upright so it cannot fall.
  - Use a proper regulator; open the valve slowly.
  - Keep away from heat; do not drop or knock it.
  - Close the valve when not filling; store and transport per the supplier's instructions.
- Follow the detailed handling rules in `hardware/` (the dispenser puts a controlled valve on the
  helium line for exactly this reason — design spec §4).

## 6. Battery safety

- Use the **smallest safe cell** that meets the buoyancy budget — small cells are lighter *and*
  store less energy, so a fault is less serious.
- **Never release a damaged, swollen, leaking or overheated cell.** It fails the pre-flight check.
- Do not short coin/film cells; keep spares in their packaging, away from metal (keys, coins).
- Dispose of cells through proper battery recycling — this is also part of
  [04 · Leave no trace](04-leave-no-trace.md).
- Keep cells away from small children and pets: coin cells are a swallowing hazard.

## 7. Pre-flight checklist

Before any show:

- [ ] Mode confirmed: **indoor / tethered** (default), or **free-release with a written permit**.
- [ ] For free-release: aviation authority permission obtained, coordinates/altitude/time filed,
      no airport or controlled/restricted airspace, weather within limits.
- [ ] No flight over crowds, roads or wildlife-sensitive areas without review.
- [ ] Ventilation adequate; helium cylinder secured; regulator fitted.
- [ ] Every unit light-tested and **logged**; released count planned to equal recovered count.
- [ ] No damaged cells; smallest safe cell used.
- [ ] Recovery plan and kit ready (see [04 · Leave no trace](04-leave-no-trace.md)).
- [ ] Start button / all-stop working; a plan to bring tethered units down is in place.

If any box is unchecked, do not fly. Run the simulator instead — it has no airspace at all.

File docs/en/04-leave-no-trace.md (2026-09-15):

# 04 · Leave no trace

> Part of Fireflies · CC BY 4.0 · © 2026 CLSOFTLAB, Dr. Lee Il-guk

> [!IMPORTANT]
> **A firefly is not litter.** Leave-no-trace is not an add-on to this project — it is one of its
> founding principles (design spec F4). This guide expands
> [design spec §7](00-design-spec.md#7-leave-no-trace-environmental-design); the spec wins if they
> disagree.

The whole idea is a riverside left exactly as you found it. Every part that flies is chosen to come
down safely and break down in nature, and every show has a recovery plan. There is **no "release
thousands and walk away" mode**, and there never will be.

## Contents

1. [The rule: released = recovered](#1-the-rule-released--recovered)
2. [Why tethered is best](#2-why-tethered-is-best)
3. [Materials](#3-materials)
4. [Recovery protocol](#4-recovery-protocol)
5. [Counting](#5-counting)
6. [After the show](#6-after-the-show)

---

## 1. The rule: released = recovered

**The number of units you release must equal the number you recover or otherwise account for.**
This one rule drives everything else: it is why we tether by default, why we log every unit, and why
we only free-release biodegradable units in a place where we can collect them.

If you cannot see how you would recover a unit, do not release it.

## 2. Why tethered is best

Tethered (or indoor) operation is the default because it makes leave-no-trace automatic:

- Each unit is on a fine, retrievable line, so **nothing is lost** — recovery is guaranteed, not
  hoped for.
- It also keeps you out of controlled airspace entirely (see
  [03 · Safety & airspace](03-safety-and-airspace.md)).
- It still looks beautiful: the units drift and sway on the wind within the length of their lines,
  and blink into sync exactly the same way.

Free-release is only for open, permitted, low-altitude sites where a full recovery sweep is possible,
using biodegradable units. Treat it as the advanced exception, not the goal.

## 3. Materials

For any free-release, choose parts that come down safely and break down:

| Part | Preferred choice | Why |
|---|---|---|
| Envelope | **Biodegradable latex** micro-balloon | Breaks down in nature far better than metallised film. Foil holds helium longer but is not biodegradable — use it only tethered-and-recovered. |
| LED carrier | **Cellulose / paper** carrier | Compostable; holds the micro-LED and circuit lightly. |
| Power | **Recoverable or compostable** cell where possible; otherwise smallest cell, fully recovered | Cells are never left in nature — recover and recycle every one. |
| Tendrils | Light, minimal material | Less material to recover; keep strands short and few. |
| Tether (tethered mode) | Fine, strong, retrievable line | The recovery guarantee. |

Metallised film, standard batteries and non-degradable plastics are acceptable **only** in
tethered-and-recovered operation, where every unit comes back.

## 4. Recovery protocol

1. **Before the show:** assign a recovery team, mark the expected drift/recovery area, and prepare
   bags, a log sheet and spare lighting for a dusk sweep.
2. **Tethered mode:** reel each unit back in; confirm each line and unit against the log.
3. **Free-release mode:** track drift, then sweep the downwind recovery area on foot at and after
   landing. Collect every unit, every fragment and every cell.
4. **Cells:** never leave a cell in nature. Bag them separately for battery recycling.
5. **Fragments:** collect balloon fragments and tendrils; latex still must be picked up even though
   it degrades.

## 5. Counting

- **Log every unit** as it is prepared and released (a simple numbered sheet is enough).
- After recovery, **reconcile:** recovered + accounted-for must equal released.
- If a unit is unaccounted for, record it, extend the sweep, and treat it as a lesson for the next
  show (fewer units, more tethering, better tracking). Publish honest counts in your
  [show report](../../.github/ISSUE_TEMPLATE/show-report.yml).

## 6. After the show

- Leave the site cleaner than you found it — pick up unrelated litter too.
- Recycle cells and any recyclable parts; compost the compostable carriers where facilities allow.
- Record what worked and what did not, so the next show recovers even more reliably.
- Share the count and lessons openly. Honest leave-no-trace reporting is part of the art.

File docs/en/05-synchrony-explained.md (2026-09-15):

# 05 · Synchrony explained

> Part of Fireflies · CC BY 4.0 · © 2026 CLSOFTLAB, Dr. Lee Il-guk

How do hundreds of little lights, with no leader and no radio, end up blinking together? This is the
heart of Fireflies, and the good news is that the idea is simple enough to explain with a stadium
crowd and a running tap. It expands [design spec §5](00-design-spec.md#5-synchronised-blinking-the-heart-of-it);
the **simulator and the firmware both run the exact model at the bottom of this page.**

## Contents

1. [The picture: a stadium of metronomes](#1-the-picture-a-stadium-of-metronomes)
2. [One firefly as a filling bucket](#2-one-firefly-as-a-filling-bucket)
3. [The nudge](#3-the-nudge)
4. [Why it ends in unison (Mirollo–Strogatz)](#4-why-it-ends-in-unison-mirollostrogatz)
5. [The exact model the sim and firmware use](#5-the-exact-model-the-sim-and-firmware-use)
6. [Things to try in the simulator](#6-things-to-try-in-the-simulator)

---

## 1. The picture: a stadium of metronomes

Imagine a stadium full of people, each clapping at their own steady pace but starting at random
moments. It sounds like noise. Now give everyone one instruction: *"each time you hear a big clap
from the crowd, clap a tiny bit sooner next time."* Nobody leads, nobody counts — yet within a
minute the whole stadium is clapping in unison. Real fireflies do the same thing with light, and so
does Fireflies. **Order emerges; nobody is in charge.**

## 2. One firefly as a filling bucket

Think of each firefly as a bucket slowly filling with water from a tap:

- The water level is the firefly's **phase**, a number that climbs smoothly from **0 to 1**.
- It takes a fixed time **T** (the *period*, about 1–2 seconds) to fill.
- The instant the bucket is full (phase reaches 1), the firefly **flashes** and the bucket
  **empties** back to 0. Then it starts filling again.

Left alone, a firefly just flashes every T seconds forever, on its own rhythm. A field of them,
started at random, flashes in a random sprinkle — no pattern.

## 3. The nudge

Now add the one rule that creates order. Each firefly can *see* light with a small sensor
(a phototransistor). **When a firefly sees a bright neighbour flash, it bumps its own water level up
a little** — by a small amount called the **coupling strength, ε (epsilon).**

That is the entire mechanism:

- If a neighbour flashes when your bucket is nearly full, the nudge tips you over the top, so you
  flash almost together **now** — and from then on you stay together.
- If it flashes when your bucket is nearly empty, the small nudge barely matters yet, but it still
  pulls you slightly toward the crowd.

Do this across a whole swarm and the flashes pull each other into step. Because the units are also
**drifting on the wind** and only see the neighbours near them, the pattern is never quite the same
twice — it forms slow, travelling waves of unison rather than a rigid all-at-once strobe. Light is
the only channel: no radio, no coordinator.

## 4. Why it ends in unison (Mirollo–Strogatz)

This "ramp up, flash, reset, and jump when you see a flash" firefly is called a **pulse-coupled
oscillator.** In 1990 Renato Mirollo and Steven Strogatz proved a beautiful result: for a large
class of such oscillators — as long as the bucket fills a little faster when it is nearly empty than
when it is nearly full (a *concave* fill curve) — **almost any starting arrangement ends up fully
synchronised.** Synchrony is not luck; it is where the system inevitably settles.

The intuition is "absorption": once two fireflies happen to flash at the same instant, the rule keeps
them together forever, so they act as one. Little synchronized groups form, then merge with other
groups, until the whole swarm is one group. Our simple *advance-by-ε* nudge is a discrete, hardware-
friendly version of the same idea, and it converges the same way.

## 5. The exact model the sim and firmware use

Both the browser simulator and the unit firmware implement the **identical** rule, so what you watch
on screen is what the hardware aims for.

**Per unit, each has:**
- `phase` ∈ [0, 1) — the water level, starts random.
- `T` — the period in seconds (default ≈ 1–2 s; the simulator's *blink period* control).
- `epsilon` (ε) — the coupling strength, a small positive number (the *coupling strength* control).
- a short **refractory** window right after its own flash, so a unit does not re-trigger on its own light.

**Every time step `dt`:**

```text
# 1. Ramp the phase forward at a steady rate 1/T.
phase = phase + dt / T

# 2. If the bucket is full, flash and reset.
if phase >= 1.0:
    flash()                 # the capacitor-boosted, spark-like pop (spec §5.1)
    phase = 0.0
    start_refractory()

# 3. If we SEE a bright neighbour flash (and we're not refractory),
#    nudge our phase forward by epsilon — never past 1.
on_neighbour_flash_seen():
    if not refractory:
        phase = min(phase + epsilon, 1.0)
        if phase >= 1.0:    # the nudge tipped us over → flash together now
            flash()
            phase = 0.0
            start_refractory()
```

Notes that keep sim and hardware honest:

- **`flash()`** is the capacitor-boosted flash of [§5.1](00-design-spec.md#51-brightness--a-spark-like-flash-without-a-spark):
  dark between flashes, a sharp bright peak — spark-*like*, with **no real spark**. Peak brightness,
  flash duration and colour are parameters; the simulator renders the same sharp profile.
- **Seeing a neighbour** in hardware is the phototransistor crossing a brightness threshold; in the
  simulator it is a neighbour flashing within a visibility radius in the drifting wind field.
- **`epsilon` small** gives gentle, slow synchrony (the pretty case); larger `epsilon` snaps into
  step faster but less softly. Wind and limited sight keep it from ever being a rigid strobe.

This is deliberately the *simplest* rule that synchronises: one phase, one threshold, one nudge. It
matches the Mirollo–Strogatz picture above closely enough that the emergent behaviour is the same,
while being tiny enough to run on an ATtiny-class chip inside a floating unit.

## 6. Things to try in the simulator

Open the [simulator](../../sim/) and experiment — it is the best way to feel the model:

- **Coupling strength ε → 0:** the nudge disappears; flashes stay a random sprinkle forever.
- **Coupling strength up:** watch small synchronized patches form, then merge into swarm-wide waves.
- **Blink period T:** longer T = slower, dreamier waves.
- **More units / stronger wind:** the pattern becomes richer and never repeats, because each unit
  only sees the neighbours the wind brings near it — the riverside feeling.

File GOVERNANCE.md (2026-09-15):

# Governance

> Part of Fireflies · CC BY 4.0 · © 2026 CLSOFTLAB, Dr. Lee Il-guk

This document explains who decides what, and how. It is deliberately simple and will grow with the
community.

한국어 요약: 프로젝트 책임자는 씨엘소프트랩(CLSOFTLAB) 이일국 박사입니다. 보통의 변경은 메인테이너
검토로 결정하고, 안전·비행·설계서에 영향을 주는 변경은 두 명의 승인과 근거가 필요합니다. 학생 기여자를
환영하고 그들의 의견을 존중합니다.

## Contents

1. [Principles](#1-principles)
2. [Roles](#2-roles)
3. [Ordinary decisions](#3-ordinary-decisions)
4. [Safety- and spec-critical decisions](#4-safety--and-spec-critical-decisions)
5. [Releases](#5-releases)
6. [Becoming a maintainer](#6-becoming-a-maintainer)
7. [Changing this document](#7-changing-this-document)

## 1. Principles

- **It stays gentle art.** Safe, non-harmful, leave-no-trace — always.
- **Safety over spectacle, evidence over opinion.** Indoor/tethered is the default; leave no trace.
- **The spec is the contract.** Behaviour changes start as changes to
  [`docs/en/00-design-spec.md`](docs/en/00-design-spec.md).
- **Open by default.** Decisions and their reasons live in public issues and pull requests, except
  security and conduct matters.
- **Welcoming, including to students.** New and young contributors are part of how this project works.

## 2. Roles

### Project lead

**Dr. Lee Il-guk (이일국), CLSOFTLAB (씨엘소프트랩)** — founder and lead.

- Sets the mission and long-term direction.
- Appoints and removes maintainers.
- Has the final say, used sparingly, especially on safety and on keeping the project gentle.

### Maintainers

- Review and merge pull requests, triage issues, and keep the simulator, hardware, firmware and docs
  coherent with the spec.
- Uphold the Code of Conduct and this document.

### Contributors

Anyone who opens an issue or pull request, builds a unit, files a show report, or improves the docs.
This includes students and first-timers, who are explicitly welcome.

## 3. Ordinary decisions

Most changes — simulator visuals, docs, refactors, non-safety fixes — need **one maintainer's
approval** on a pull request, with CI passing. Disagreements are resolved by discussion; if needed,
the project lead decides.

## 4. Safety- and spec-critical decisions

A change is safety- or spec-critical if it touches:

- the sync model, the flash (§5.1), buoyancy trim, or the dispenser's fill / trim / self-test /
  release / all-stop logic;
- the safety and airspace guidance, or the leave-no-trace rules;
- helium or battery handling;
- the design spec's behaviour (English **and** the Korean 설계서).

These need **two approvals, including one maintainer**, plus evidence (test results, a bench or show
report, or a clear argument). The spec is updated in the same change. When in doubt, treat a change as
safety-critical.

## 5. Releases

- Releases are tagged from `main` with CI green.
- Each release notes what changed, and flags any safety- or spec-affecting change.
- Security fixes may be released out of the normal cadence.

## 6. Becoming a maintainer

Maintainers are invited by the project lead after a track record of good, kind contributions and sound
judgement on safety. Say if you would like to help more — we are glad to grow the team, students
included.

## 7. Changing this document

Propose changes by pull request. Changes to governance need the project lead's approval and are
announced openly.

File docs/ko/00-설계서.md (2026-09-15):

# 반딧불이 (Fireflies) — 설계서 (v0.1)

> 반딧불이 프로젝트의 일부 · CC BY 4.0 · © 2026 씨엘소프트랩, 이일국 박사

> **상태:** 개념 + 기준 설계 v0.1 · **유일한 기준 문서.** 브라우저 시뮬레이터, 디스펜서 하드웨어,
> 반딧불이 개체, 모든 가이드는 이 문서를 따릅니다. 먼저 이 문서를 고치고, 그다음 구현을 고치세요.

- 프로젝트: **반딧불이 (Fireflies)** — 열려 있고 온화한 밤하늘 예술 설치입니다. 아주 가볍고 스스로
  빛나는 LED **하늘해파리(해파리)** — 빛나는 촉수를 단 헬륨 마이크로 풍선 — 수백 마리를 공중으로
  놓아 보내고 **바람에 떠다니도록** 둡니다. 촉수가 흔들리고 그 위로 빛이 흘러내리며, 밤바다를
  떠도는 해파리처럼 느리고 스스로 조직되는 동기화로 깜빡입니다(§3.1). v1 형태는 **하늘해파리**이고,
  단일 점광원인 평범한 "반딧불이"는 더 단순한 변형입니다.
- 프로젝트 책임자: **씨엘소프트랩(CLSOFTLAB), 이일국 박사**
- 기여자: **LWJ**(경기도, 고등학생), **LMJ**(경기도, 중학생)
- Claude(Anthropic의 AI)와 함께 설계했습니다. Anthropic의 제품이 아닙니다.
- 라이선스: 소프트웨어 Apache-2.0 · 하드웨어 CERN-OHL-P-2.0 · 문서 CC BY 4.0.

---

## 1. 이것은 무엇이고, 무엇이 아닌가

이 아이디어는 강가에서 시작했습니다. 노을 무렵, 작은 벌레 구름이 공기에 밀려 떠다니고 소용돌이치며,
진짜 반딧불이가 서서히 하나로 맞아 들어가는 리듬으로 깜빡입니다. 반딧불이는 그 느낌을 엄지손톱만 한
빛 수백 개로 다시 만듭니다.

**핵심 설계 선택: 우리는 그들이 어디로 갈지 통제하지 않습니다.** 버튼 하나가 공연을 "시작"합니다 —
개체를 놓아 보내고 불을 켭니다 — 그다음부터는 **바람이 데려갑니다.** GPS도, 위치 유지도, 대형도,
조종도 없습니다. 흩어지는 것은 실패가 아니라, 그것이 *바로 작품입니다.*

이 점이 반딧불이를 상업용 드론 라이트쇼(각 드론을 정밀하게 배치해 글자와 로고를 그리는)와 근본적으로
다르게 만듭니다. 또한 훨씬 단순하고, 훨씬 저렴하고, 진짜 엄지손톱만큼 작을 수 있게 합니다.

| # | 원칙 | 결과 |
|---|---|---|
| F1 | **안무는 바람에게 맡긴다** | GPS 없음, 위치 제어 없음, 충돌 회피 없음. 각 개체는 오직 뜨고 깜빡일 뿐. |
| F2 | **겨우 뜨는 정도의 양력** | 각 반딧불이는 거의 중립 부력으로 다듬은 헬륨 마이크로 풍선이라, 솟구치지 않고 매달려 떠다닌다. |
| F3 | **지휘자 없이 동기화로 깜빡인다** | 각 개체는 자기가 볼 수 있는 이웃 쪽으로 깜빡임을 살짝 당긴다(펄스 결합 진동자, 진짜 반딧불이처럼). 질서는 떠오르고, 아무도 지휘하지 않는다. |
| F4 | **흔적을 남기지 않는다** | 나는 모든 부품은 안전하게 내려와 자연에서 분해되도록 고르고, 회수 계획을 둔다. 이것은 반딧불이이지 쓰레기가 아니다. §7 참고. |
| F5 | **온화하고 합법적** | 낮은 고도, 계류 또는 울타리 옵션, 명확한 항공 규칙, 항공기·사람·야생에 위험 없음. §6 참고. |
| F6 | **누구나 만들 수 있다** | 전 세계에서 구할 수 있는 부품, "기계"는 3D 프린팅 디스펜서 하나, 시뮬레이터는 아무 브라우저에서 실행. |
| F7 | **먼저, 어떤 규모로든 시뮬레이션한다** | 브라우저 시뮬레이터에는 크기나 수의 한계가 없다: 엄지손톱 반딧불이 수천 마리가 떠다니며 동기화되는 꿈을, 링크로 볼 수 있다. 현실은 그 옆에 정직하게 기록한다. |
| F8 | **열린 라이선스** | Apache-2.0 / MIT / BSD / CC-BY 만. |

---

## 2. 시스템 개요

```
   ┌──────────────── 디스펜서 ("기계") ────────────────┐        바람
   │  헬륨 미세 충전  →  부력 다듬기  →  LED 장착 및 시험  │           ↓
   │  →  한 번에 하나씩 반딧불이 방출     ← 시작 버튼        │   ✦   ✧      ✦
   │  (§4)                                                │      ✧   ✦  ✧     ✦
   └───────────────────────────┬──────────────────────────┘   ✦      ✧      ✦
                               │ 방출                          떠다니며 깜빡임
                               ▼                              느린 동기화로 (§5)
                    ┌──── 반딧불이 개체 (§3) ────┐
                    │ 마이크로 풍선 (He)          │
                    │ + 마이크로 LED + 코인 전지  │
                    │ + 작은 깜빡임 회로          │
                    │ 거의 중립 부력              │
                    └────────────────────────────┘

   브라우저 시뮬레이터 (§8): 반딧불이 수천 마리를 방출하여 바람장 위에서 떠다니게 하고,
   동기화로 깜빡이게 한다 — 하드웨어 불필요, 링크로 공유 가능.
```

두 트랙, 둘 다 오픈소스입니다.
- **시뮬레이터 트랙**(주력): 오늘 당장 전 규모로 꿈이 돌아가는 브라우저 세계.
- **하드웨어 트랙**(기준 설계): 반딧불이 개체와 디스펜서 기계. 물리가 실제 크기와 비행 시간을 제한하는
  지점까지 정직하게 기록.

---

## 3. 반딧불이 개체 (기준 설계, 하드웨어 트랙)

목표: 실내/아주 약한 바람의 공기에서 떠다니는, 가장 작고 가장 가벼운 자체 발광 부유체.

| 부품 | 선택 | 비고 |
|---|---|---|
| 외피 | 금속 필름("포일 풍선") 마이크로 버블 ~5–8 cm, 또는 생분해 라텍스 마이크로 풍선 | 포일은 헬륨을 더 오래 잡고, 라텍스는 더 잘 분해된다(§7). 엄지손톱 크기(2 cm)는 오늘날 **시뮬레이터 전용** 꿈이다. 전자부품을 조금이라도 들 수 있는 실제 풍선은 더 크다. 정직하게 기록한다. |
| 양력 기체 | 헬륨, **거의 중립 부력**으로 다듬음 | 빠르게 오르지도 가라앉지도 않을 때까지 채운다. 매달려 떠다녀야 한다. 다듬기가 핵심 기술(§4). |
| 빛 | 마이크로 LED 1개, 따뜻한 앰버 기본 + **커패시터로 부스팅한 밝은 번쩍임** | 앰버 ~590 nm는 반딧불이와 맞는다. 번쩍임은 노을에도 보이는 날카롭고 불꽃 같은 "팟"을 준다(§5.1 참고). |
| 전원 | 부력 예산 안에서 뜨는 가장 작은 코인/필름 전지 | 풍선 크기와 깜빡임 듀티에 따라 몇 분에서 두어 시간. |
| 깜빡임 회로 | 작은 마이크로컨트롤러(ATtiny급) 또는 개별 아날로그 블링커 | 펌웨어 옵션은 광센서로 동기화(§5)를 켠다. 아날로그 옵션은 그냥 깜빡인다. |
| 동기화 센서(선택) | 광트랜지스터 1개 | 이웃의 번쩍임을 보고 리듬에 맞춰 들어간다. |
| 질량 예산 | 전부 풍선의 자유 양력 이하 | 탑재물이 가벼울수록 풍선이 작아질 수 있다. 매 밀리그램을 최소화한다. |

### 3.1 두 형태: 반딧불이와 하늘해파리

떠다니고, 바람에 흐르고, 스스로 깜빡이는 같은 개체가 두 가지 시각 형태로 나옵니다.

- **반딧불이 형태:** 깜빡이는 하나의 빛점 — 강 위에 흩뿌려진 불꽃.
- **하늘해파리 형태(해파리):** 헬륨 풍선이 *몸통(bell)*이고, 거기에서 아주 가볍고 빛나는 **촉수**
  여러 가닥이 늘어집니다 — 가는 전도성 실이나 마이크로 필름 리본에 마이크로 LED가 줄지어 달립니다.
  공중에서 촉수는 해류를 탄 해파리처럼 바람을 따라 흔들리고 끌립니다 — 이것이 바로 "바람이 데려가게
  둔다"는 생각(F1)을 눈에 보이게 만든 것입니다. 촉수 설계:
  - **몸통:** 헬륨 마이크로 풍선이 모든 양력을 제공한다. 촉수는 깃털처럼 가볍게 유지해 부력이 거의
    영향받지 않게 한다(촉수의 매 밀리그램이 자유 양력 예산 안에 있어야 한다).
  - **촉수:** 3~8가닥, 각각 마이크로 LED 몇 개. 가닥은 뻣뻣하지 않고 부드럽게 매달려 흔들릴 만큼
    가벼워야 한다.
  - **흐르는 빛:** 빛을 촉수를 따라 **위→아래로** 느린 물결로 흘려서, 해파리가 맥동하며 헤엄치는
    것처럼 보이게 한다(많은 실제 해파리는 이동하는 파동으로 빛난다).
  - **몸통의 불꽃 번쩍임:** 부드럽게 흐르는 촉수 위로, 몸통에서 이따금 커패시터로 부스팅한 번쩍임(§5.1)이
    점화원 없이 선명한 "팟"을 준다.

시뮬레이터는 두 형태를 모두 렌더링합니다. 하늘해파리는 바람장 안에서 흔들리고 빛이 흐르며 끌리는
촉수를 단 몸통으로 그립니다.

**정직한 한계:** 마이크로 LED, 전지, 회로를 싣고도 여전히 뜨는 진짜 2 cm 엄지손톱 개체는 오늘날 기성
부품으로 존재하지 않습니다. 기준 *하드웨어* 개체는 실제로 만들 수 있는 가장 작은 것이고(`hardware/`에
기록), *시뮬레이터*는 2 cm의 꿈을 렌더링합니다.

---

## 4. 디스펜서 기계

날 풍선 + 헬륨 공급원을 완성된, 빛나는, 중립으로 다듬어진 반딧불이로 바꾸고 버튼으로 방출하는, 3D
프린팅 가능한 데스크톱 기계 하나입니다.

단계:
1. **적재** — 매거진에서 빈 외피를 하나 넣는다.
2. **충전** — 목표 자유 양력까지 헬륨을 채운다. 작은 로드셀/저울로 측정해 부력을 **거의 중립으로
   다듬는다**(F2 뒤에 있는 성패의 단계). 펌웨어가 목표에서 밸브를 닫는다.
3. **장착 및 무장** — LED 탑재물을 붙이고, **점등 자가 시험**(한 번 깜빡)을 돌려 죽은 개체가 방출되지
   않게 한다.
4. **방출** — 운영자의 시작 신호에 따라 한 번에 하나씩, 또는 부드러운 리듬으로 방출한다.
5. **시작 버튼 / 휴대 리모컨** — 유일한 실시간 제어("방출 시작"). 또한 **전체 정지**(방출 중지)이며,
   계류 개체를 내리는 문서화된 계획도 포함한다.

기준 제작: 라즈베리 파이 피코 또는 아두이노급 컨트롤러, 헬륨 라인의 마이크로 서보/솔레노이드 밸브,
부력용 로드셀 + HX711급 증폭기, LED 시험용 포토다이오드, 3D 프린팅 프레임, 매거진, 방출 게이트.
전체 BOM과 배선은 `hardware/`에.

---

## 5. 동기화된 깜빡임 (이 프로젝트의 심장)

지휘자 없는 진짜 반딧불이도 하나로 맞춰 번쩍입니다. 각 반딧불이는 **펄스 결합 진동자**로 모델링됩니다.
내부 위상이 임계값까지 차오르다가 번쩍이고 리셋됩니다. 이웃이 번쩍이는 것을 *보면* 자기 위상을 조금
앞으로 당깁니다. 무리 전체에서 이것은 동기화로 수렴합니다(Mirollo–Strogatz). 우리는 같은 규칙을
구현합니다.

- 각 개체는 위상을 주기 T(≈ 1–2초) 동안 0→1로 차오르게 하고, 1에서 번쩍이고, 리셋한다.
- 밝은 이웃의 번쩍임을 보면(광트랜지스터) 위상을 작은 결합 ε만큼 앞당긴다.
- 결과: 제멋대로 시작한 반딧불이들이 서서히 함께 깜빡인다 — 바람과 떠다님이 패턴을 결코 똑같지 않게
  만든다. 무선도, 조정자도 없다. 빛이 유일한 채널이다.

**시뮬레이터**는 동일한 모델을 구현하므로, 화면에서 보는 것이 곧 하드웨어가 지향하는 것입니다.

### 5.1 밝기 — 불꽃 없는 불꽃 같은 번쩍임

가만히 켜진 마이크로 LED 하나는 노을에 보기엔 너무 어둡습니다. 그런데 반딧불이 공연이 마법 같은 때가
바로 그 노을입니다. 우리는 전기 불꽃의 날카롭고 밝은 "팟"을 원하지만, **나는 개체에 진짜 불꽃이나
어떤 점화원도 절대 싣지 않습니다.** 자유롭게 떠다니는 물체는 어디든(마른 풀, 사람들, 지붕) 내려앉을
수 있고, 불꽃은 화재 위험입니다. 또한 불꽃은 반딧불이의 부드럽게 반복되는 깜빡임이 아니라 한 번의
"클릭"입니다.

대신 각 반딧불이는 **커패시터로 부스팅한 LED 번쩍임**을 만듭니다. 작은 커패시터가 조용히 충전되었다가
LED로 짧고 강하게 쏟아부어, 카메라 플래시나 자전거 후미등 스트로브처럼 됩니다. 번쩍임 사이에는 어둡고
절정에서 확 밝아져, 선명한 불꽃 같은 "팟"을 주며 노을 진 하늘 멀리서도 보입니다. 앰버에 **차가운
흰색/파란색**을 살짝 섞으면 전기 불꽃의 색까지 흉내 낼 수 있습니다. 불길 없음, 점화 없음, 마이크로
풍선이 들 만큼 가벼움. 절정 밝기, 번쩍임 지속시간, 색은 펌웨어 파라미터입니다. 시뮬레이터는 동일한
날카로운 번쩍임 프로파일을 렌더링합니다.

---

## 6. 안전과 항공 (실제 비행 전 필독)

- **항공기 안전이 최우선.** 공항 근처나 관제 공역의 자유 부유 발광 물체는 위험하며 대부분의 나라에서
  규제됩니다(한국에서는 항공안전법이 라이트쇼, 풍선 방출, 모든 비행 장치를 규율하며, 허가와 좌표가
  필요합니다). 어디서나 완전히 합법인 기본 모드는 **실내** 또는 **계류**(각 반딧불이를 가는 줄에
  매달아 회수 가능)입니다.
- **자유 방출**(진짜 바람 표류)은 개방되고 낮은 고도의 허가받은 장소에서, 지역 항공 당국과 협의한
  경우에만 — "고급 / 허가 필요"로 기록하며 결코 기본이 아닙니다.
- 군중, 도로, 야생 민감 지역 위로는 검토 없이 비행하지 않습니다.
- 헬륨은 밀폐 공간에서 질식 위험이고 실린더는 고압입니다 — 취급 규칙은 `hardware/`에.
- 배터리: 가장 작은 안전한 전지를 쓰고, 손상된 전지는 절대 방출하지 않습니다.

## 7. 흔적을 남기지 않기 (환경 설계)

- **계류 + 회수** 운용을 우선합니다(아무것도 잃지 않음).
- 자유 방출을 하는 경우: **생분해 외피**, **셀룰로스/종이 LED 캐리어**, 가능한 곳에서는 **회수 가능하거나
  퇴비화되는** 전원을 씁니다. 몇 개를 방출했는지 기록하고 이후 회수를 조직합니다. 방출한 수는 회수/확인한
  수와 같아야 합니다.
- 이 프로젝트는 "수천 개 날리고 그냥 떠나는" 모드를 공개하지 않습니다. 쓰레기는 반딧불이의 반대입니다.

---

## 8. 브라우저 시뮬레이터 (주력 산출물)

빌드 단계도 외부 서비스도 없는 단일 페이지 웹 앱으로, 전 규모의 꿈을 보여줍니다.
- **바람장**(부드럽고 시간에 따라 변하는)이 반딧불이 수천 마리를 떠다니게 한다. 그들은 퍼지고,
  소용돌이치고, 결코 반복되지 않는다 — 강가의 느낌.
- 각 반딧불이는 **펄스 결합 동기화** 모델(§5)을 돌린다. 관객은 제멋대로인 깜빡임이 느린 하나의
  물결로 모이는 것을 지켜본다.
- 아래쪽 **디스펜서**가 "시작" 버튼에 따라 시간에 걸쳐 반딧불이를 방출한다. 하드웨어 이야기와 맞춘다.
- 컨트롤: 반딧불이 수, 바람 세기, 깜빡임 주기, 결합 세기, 색. 일시정지. "흔적을 남기지 않기" 메모.
  접근성(키보드, 모션 감소, 고대비), 반응형, 라이트/다크.
- 일반 노트북에서 수천 개로 실행되고, 휴대폰에서는 우아하게 성능을 낮춘다.

## 9. 저장소 구조

```
docs/en, docs/ko          설계서, 제작 가이드, 안전, 환경
sim/                      브라우저 시뮬레이터(HTML/CSS/JS, 빌드 없음), 테스트
hardware/                 반딧불이 개체 + 디스펜서: OpenSCAD 부품, BOM, 배선, 펌웨어
firmware/                 깜빡임 + 동기화 펌웨어(개체)와 디스펜서 컨트롤러
site/                     프로젝트 페이지(선택)
```

## 10. 단계

| 단계 | 범위 |
|---|---|
| P0 | 브라우저 시뮬레이터: 수천 개 규모의 바람 표류 + 펄스 결합 동기화 |
| P1 | 벤치 위 반딧불이 개체 하나: 깜빡임 + 빛으로 2~5개 간 동기화 |
| P2 | 디스펜서 기계: 헬륨 충전 + 부력 다듬기 + LED 시험 + 방출, 실내/계류 |
| P3 | 계류 실내 공연(회수 가능), 10~50개 |
| P4 | 자유 방출 — 허가, 생분해 개체, 완전 회수가 있을 때만(고급) |

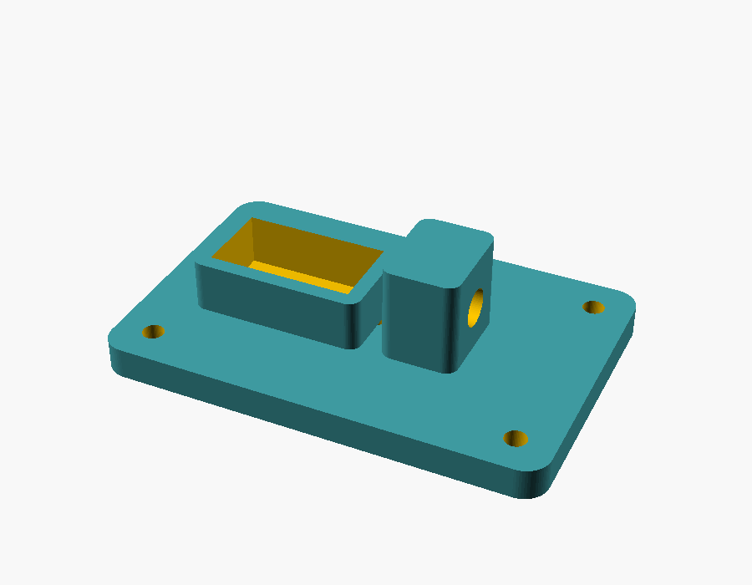
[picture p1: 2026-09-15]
hardware/renders/servo_valve_mount.png

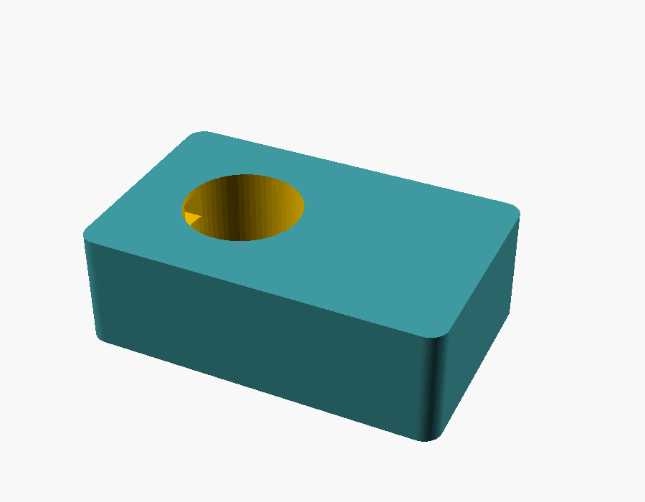
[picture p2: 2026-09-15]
hardware/renders/release_gate.png

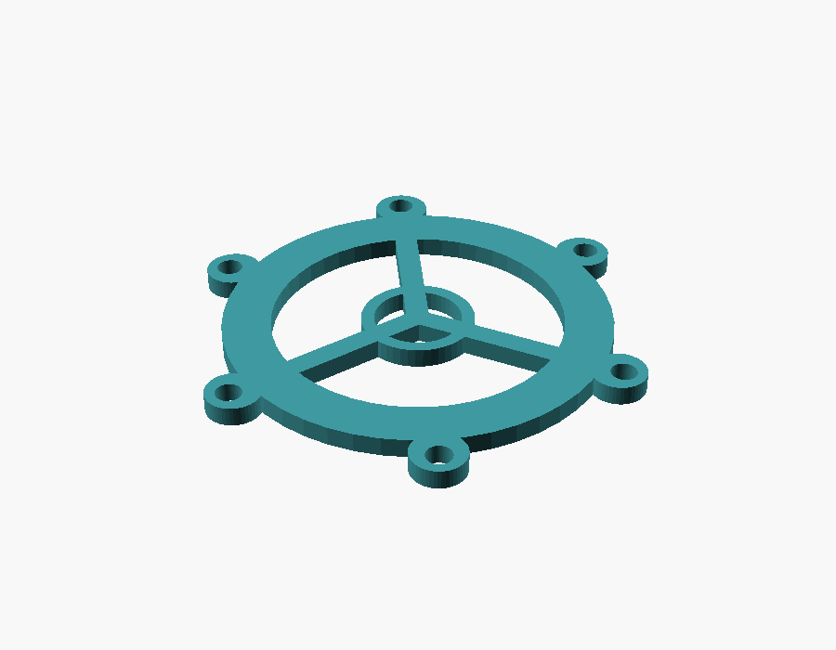
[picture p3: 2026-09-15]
hardware/renders/jellyfish_carrier.png

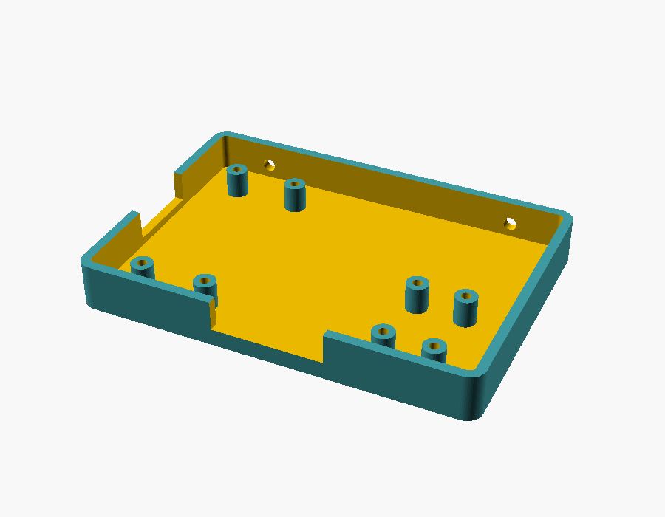
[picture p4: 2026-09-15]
hardware/renders/electronics_tray.png

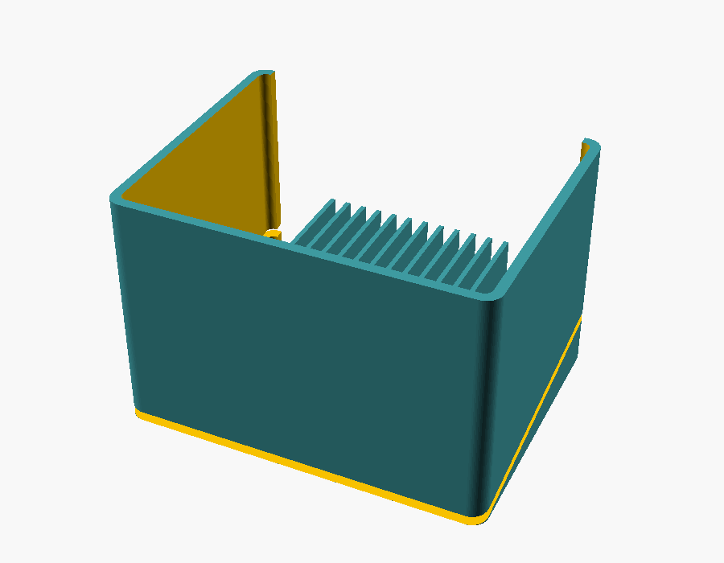
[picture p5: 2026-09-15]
hardware/renders/balloon_magazine.png

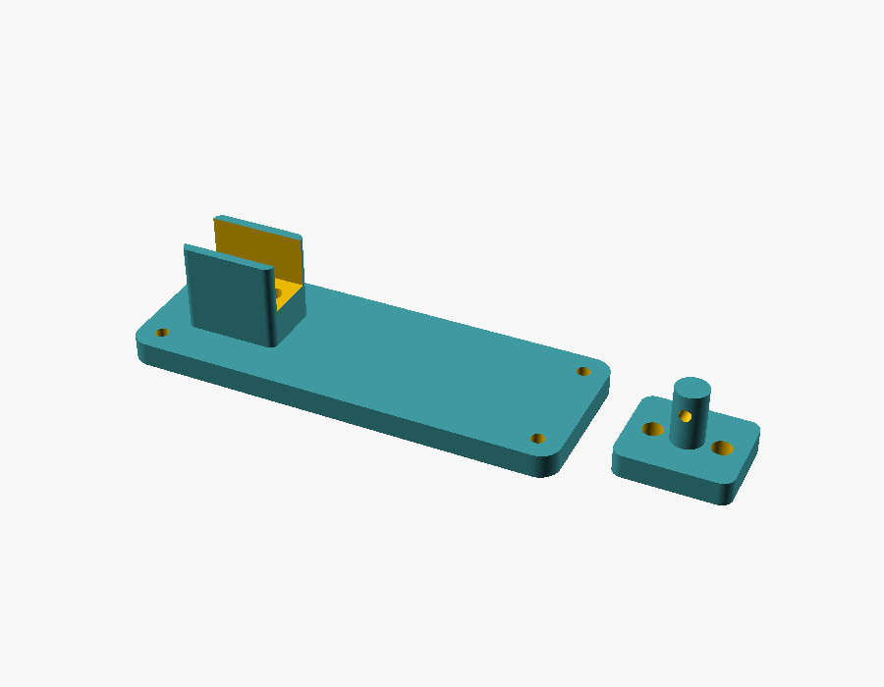
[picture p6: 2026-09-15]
hardware/renders/load_cell_mount.png

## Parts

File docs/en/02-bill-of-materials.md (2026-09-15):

# 02 · Bill of materials

> Part of Fireflies · CC BY 4.0 · © 2026 CLSOFTLAB, Dr. Lee Il-guk

> [!IMPORTANT]
> **This list is provisional.** It is written from [design spec](00-design-spec.md) §3 (firefly
> unit) and §4 (dispenser) while the hardware track is being built. When `hardware/README.md`
> exists, **that file is the authoritative BOM** — quantities, exact part numbers and verified
> buying links live there. Prices below are rough ranges (USD) for planning only and vary by
> country and supplier. See the machine-readable summary in [`bom.csv`](../bom.csv).

Licences: hardware design files are CERN-OHL-P-2.0; the parts themselves are ordinary commodity
components. Use permissively-licensed firmware/tools only (Apache-2.0 / MIT / BSD).

---

## A. Firefly / sky-jellyfish unit (per unit)

The goal is the smallest, lightest self-lit floater. Minimise every milligram: the lighter the
payload, the smaller the balloon can be.

| # | Part | Choice / spec | Qty | Rough price | Notes |
|---|---|---|---|---|---|
| U1 | Envelope (bell) | Metallised-film micro-bubble ~5–8 cm **or** biodegradable latex micro-balloon | 1 | $0.20–1.00 | Foil holds helium longer; latex breaks down better (§7). 2 cm is simulator-only. |
| U2 | Lift gas | Helium, trimmed to near-neutral buoyancy | as needed | see D1 | ~1 g lift per litre displaced. Trim is the key skill. |
| U3 | Light | Micro-LED, warm amber ~590 nm (+ optional cool-white/blue tint) | 1 | $0.05–0.30 | Amber matches fireflies; blue tint mimics a spark's colour. |
| U4 | Flash capacitor | Small ceramic/film cap for the capacitor-boosted flash | 1 | $0.05–0.20 | Gives the sharp, spark-like *pop* (§5.1) — **no real spark**. |
| U5 | Power | Smallest coin/film cell inside the lift budget | 1 | $0.10–0.50 | Runtime minutes to a couple of hours. Never fly a damaged cell. |
| U6 | Blink circuit | ATtiny-class microcontroller **or** discrete analog blinker | 1 | $0.30–1.50 | Firmware enables synchrony; analog just blinks. |
| U7 | Sync sensor (optional) | Phototransistor | 0–1 | $0.05–0.30 | Sees neighbours' flashes to fall into rhythm. |
| U8 | Tendrils (jellyfish form) | 3–8 light strands (thin conductive thread / micro-film ribbon), a few micro-LEDs each | 3–8 | $0.20–1.00 total | Must hang and sway; every milligram inside the free-lift budget. |
| U9 | Carrier / attachment | Cellulose or paper LED carrier, light tether point | 1 | $0.02–0.10 | Biodegradable carrier preferred for free-release (§7). |

**Indicative unit cost:** roughly **$1–5** in small quantities, dominated by the balloon and cell.

---

## B. Dispenser machine (one, reusable)

One 3D-printable desktop machine (design spec §4). Reusable across every show.

| # | Part | Choice / spec | Qty | Rough price | Notes |
|---|---|---|---|---|---|
| D1 | Helium source | Small helium cylinder + regulator | 1 | $30–80 | High-pressure; asphyxiant in enclosed spaces. Handle per `hardware/`. |
| D2 | Controller | Raspberry Pi Pico **or** Arduino-class board | 1 | $4–12 | Runs fill/trim/test/release. |
| D3 | Fill valve | Micro servo **or** solenoid valve on the helium line | 1 | $3–15 | Firmware closes it at target free-lift. |
| D4 | Buoyancy balance | Load cell + HX711-class amplifier | 1 | $3–8 | Measures free-lift so the unit is trimmed near neutral (§F2). |
| D5 | LED self-test | Photodiode | 1 | $0.20–1.00 | Confirms one blink so no dead unit is released. |
| D6 | Frame / magazine / release gate | 3D-printed parts (PLA/PETG) | 1 set | $2–8 filament | OpenSCAD sources in `hardware/` (CERN-OHL-P-2.0). |
| D7 | Start button / all-stop | Momentary button **or** handheld remote | 1 | $1–10 | The only live control: begin releasing / all-stop. |
| D8 | Wiring & misc | Dupont wire, headers, small fasteners | — | $2–6 | Per wiring diagram in `hardware/`. |

**Indicative dispenser cost:** roughly **$50–150** once, plus filament and helium refills.

---

## C. Consumables & recovery kit (per show)

| # | Part | Notes |
|---|---|---|
| C1 | Fine tether line (spools) | For the default tethered mode — retrievable. |
| C2 | Recovery bags / log sheet | Released count **must** equal recovered count (§7). |
| C3 | Spare cells, spare envelopes | Never fly a damaged cell. |

---

## D. Simulator

**$0.** The [simulator](../../sim/) runs in any browser with no hardware and no build step. Tests run
with `node --test sim/tests` (Node.js 20+).

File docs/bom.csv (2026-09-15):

ref | group | part | choice_spec | qty | price_low_usd | price_high_usd | licence_or_notes | status
U1 | unit | Envelope (bell) | Metallised-film micro-bubble ~5-8cm or biodegradable latex micro-balloon | 1 | 0.20 | 1.00 | Foil holds helium longer; latex breaks down better; 2cm is simulator-only | provisional
U2 | unit | Lift gas | Helium trimmed to near-neutral buoyancy | 1 | 0 | 0 | ~1 g lift per litre displaced; see D1 for source | provisional
U3 | unit | Light | Micro-LED warm amber ~590nm (+ optional cool-white/blue tint) | 1 | 0.05 | 0.30 | Amber matches fireflies; blue tint mimics spark colour | provisional
U4 | unit | Flash capacitor | Small ceramic/film capacitor for capacitor-boosted flash | 1 | 0.05 | 0.20 | Gives spark-like pop (spec 5.1) with no real spark | provisional
U5 | unit | Power | Smallest coin/film cell inside lift budget | 1 | 0.10 | 0.50 | Never fly a damaged cell | provisional
U6 | unit | Blink circuit | ATtiny-class microcontroller or discrete analog blinker | 1 | 0.30 | 1.50 | Firmware enables synchrony; analog just blinks | provisional
U7 | unit | Sync sensor (optional) | Phototransistor | 1 | 0.05 | 0.30 | Sees neighbours flashes to fall into rhythm | provisional
U8 | unit | Tendrils (jellyfish form) | 3-8 light strands with a few micro-LEDs each | 8 | 0.20 | 1.00 | Must hang and sway; every milligram inside free-lift budget | provisional
U9 | unit | Carrier/attachment | Cellulose or paper LED carrier + light tether point | 1 | 0.02 | 0.10 | Biodegradable carrier preferred for free-release | provisional
D1 | dispenser | Helium source | Small helium cylinder + regulator | 1 | 30 | 80 | High-pressure; asphyxiant in enclosed spaces | provisional
D2 | dispenser | Controller | Raspberry Pi Pico or Arduino-class board | 1 | 4 | 12 | Runs fill/trim/test/release | provisional
D3 | dispenser | Fill valve | Micro servo or solenoid valve on helium line | 1 | 3 | 15 | Firmware closes at target free-lift | provisional
D4 | dispenser | Buoyancy balance | Load cell + HX711-class amplifier | 1 | 3 | 8 | Trims unit near neutral (F2) | provisional
D5 | dispenser | LED self-test | Photodiode | 1 | 0.20 | 1.00 | Confirms one blink so no dead unit released | provisional
D6 | dispenser | Frame/magazine/release gate | 3D-printed parts (PLA/PETG) | 1 | 2 | 8 | OpenSCAD sources in hardware/ (CERN-OHL-P-2.0) | provisional
D7 | dispenser | Start button/all-stop | Momentary button or handheld remote | 1 | 1 | 10 | Only live control: begin releasing / all-stop | provisional
D8 | dispenser | Wiring & misc | Dupont wire headers small fasteners | 1 | 2 | 6 | Per wiring diagram in hardware/ | provisional
C1 | consumable | Fine tether line | Spools for default tethered mode | 1 | 2 | 10 | Retrievable | provisional
C2 | consumable | Recovery bags / log sheet | For counting | 1 | 1 | 5 | Released count must equal recovered count | provisional
C3 | consumable | Spares | Spare cells and envelopes | 1 | 2 | 10 | Never fly a damaged cell | provisional

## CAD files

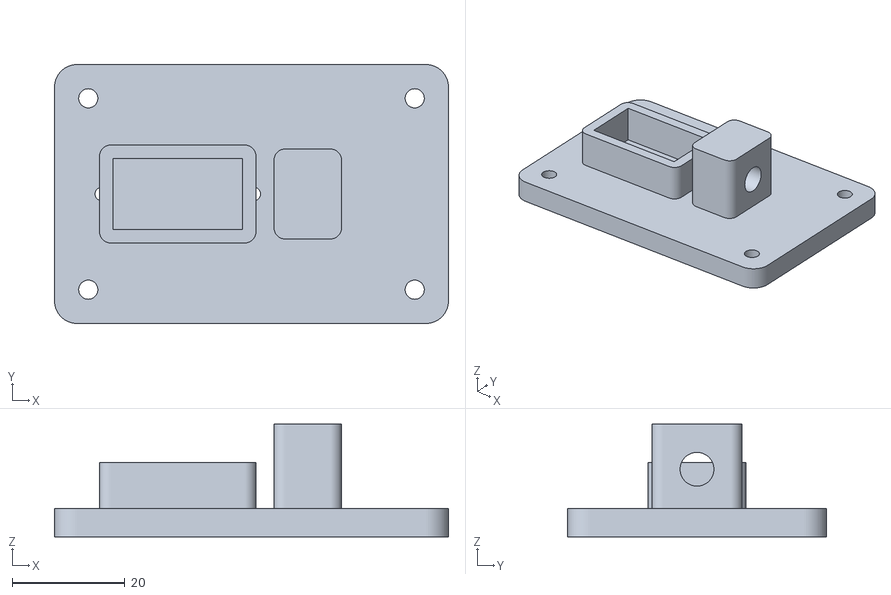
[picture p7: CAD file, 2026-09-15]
hardware/stl/servo_valve_mount.stl
70.0 x 46.0 x 20.0

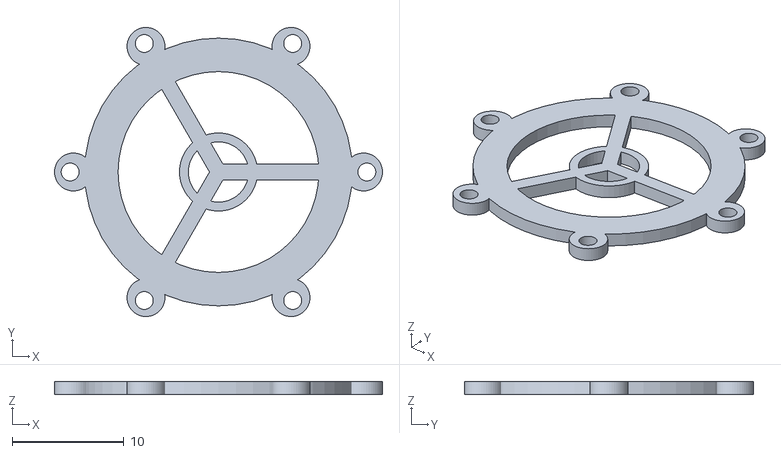
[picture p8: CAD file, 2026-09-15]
hardware/stl/jellyfish_carrier.stl
29.4 x 25.9 x 1.20

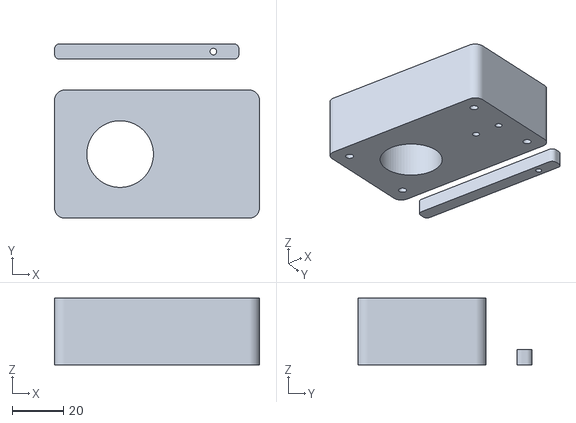
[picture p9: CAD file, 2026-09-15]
hardware/stl/release_gate.stl
80.0 x 68.0 x 26.0

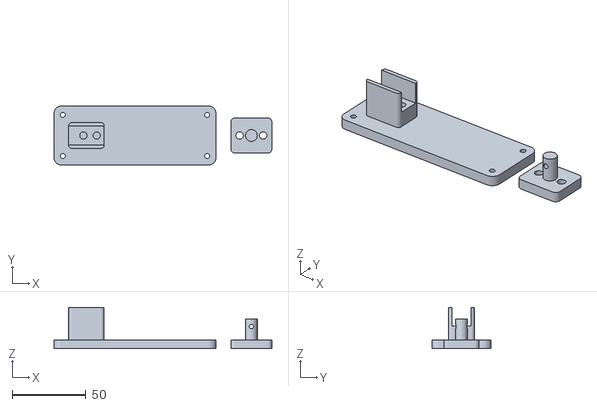
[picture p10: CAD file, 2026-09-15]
hardware/stl/load_cell_mount.stl
148.0 x 40.0 x 28.0

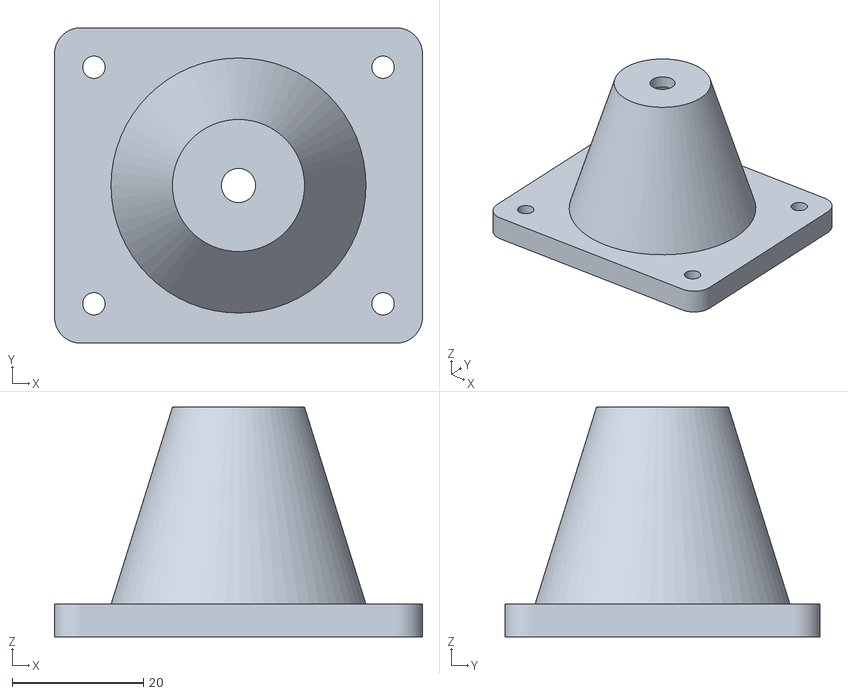
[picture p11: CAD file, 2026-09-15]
hardware/stl/led_test_jig.stl
56.0 x 48.0 x 35.0

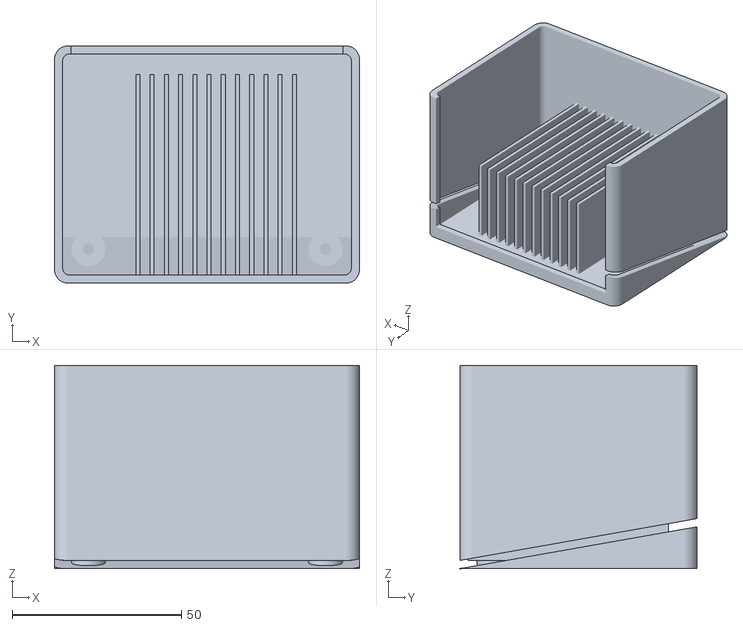
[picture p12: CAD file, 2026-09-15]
hardware/stl/balloon_magazine.stl
90.0 x 70.0 x 60.0

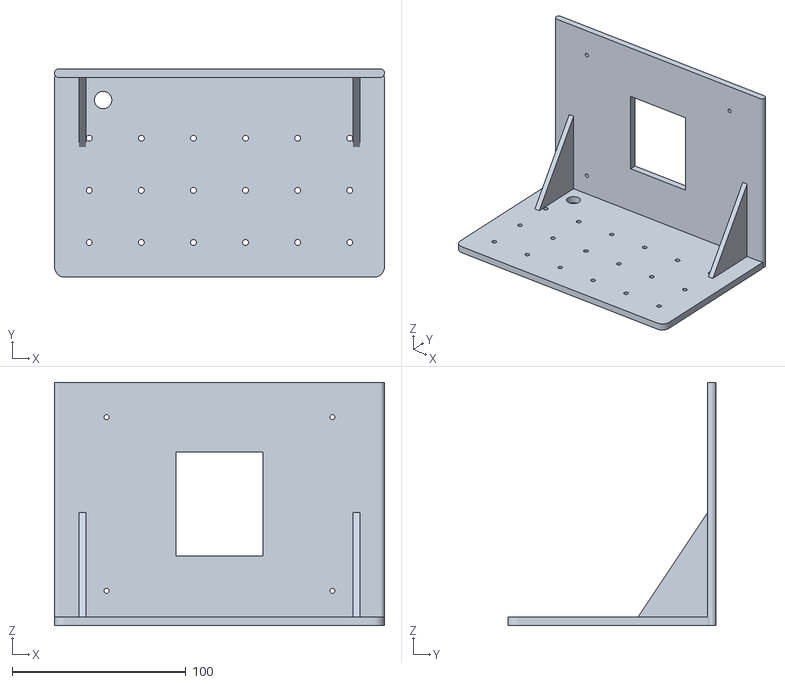
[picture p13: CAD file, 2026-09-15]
hardware/stl/dispenser_frame.stl
190.0 x 120.0 x 140.0

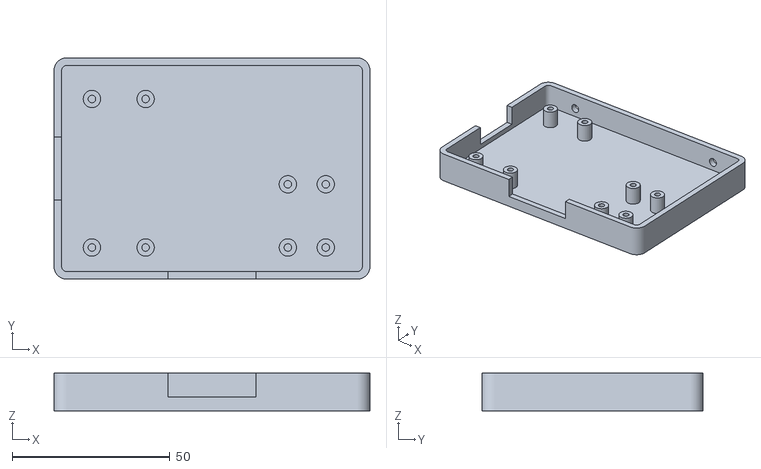
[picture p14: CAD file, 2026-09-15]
hardware/stl/electronics_tray.stl
100.0 x 70.0 x 12.0

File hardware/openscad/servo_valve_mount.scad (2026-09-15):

// SPDX-License-Identifier: CERN-OHL-P-2.0
// SPDX-FileCopyrightText: 2026 CLSOFTLAB / Dr. Lee Il-guk (이일국) and Fireflies contributors
//
// servo_valve_mount.scad — holds a 9g micro-servo whose horn pinches the soft
// helium tube against an anvil (a pinch valve). The buoyancy loop opens/closes this
// to meter helium (spec §4, F2). No high-pressure parts here: it pinches a low-
// pressure silicone line downstream of the regulator.

include <lib/common.scad>

SERVO_L = 23.0;   // SG90-class body length
SERVO_W = 12.6;   // body width
SERVO_H = 22.0;   // body height (below flange)
FLANGE  = 32.5;   // tab-to-tab length
TUBE_OD = 6.0;    // silicone helium tube outer diameter

BASE_W = 70; BASE_D = 46; BASE_T = 5;

module servo_valve_mount() {
    difference() {
        union() {
            rounded_box([BASE_W, BASE_D, BASE_T], r=4);
            // servo pocket walls
            translate([8, BASE_D/2 - SERVO_W/2 - WALL, 0])
                rounded_box([SERVO_L + 2*WALL, SERVO_W + 2*WALL, SERVO_H*0.6], r=2);
            // anvil block the tube is pinched against
            translate([8 + SERVO_L + 8, BASE_D/2 - 8, 0])
                rounded_box([12, 16, 20], r=2);
        }
        // servo body cavity
        translate([8+WALL, BASE_D/2 - SERVO_W/2, BASE_T])
            cube([SERVO_L, SERVO_W, SERVO_H]);
        // servo flange screw holes
        for (dx = [8+WALL - 2, 8+WALL + SERVO_L + 2])
            translate([dx, BASE_D/2, -EPS]) cylinder(d=2.4, h=BASE_T+2*EPS);
        // tube groove across the anvil so the horn can pinch it
        translate([8 + SERVO_L + 6, BASE_D/2, 12])
            rotate([0,90,0]) cylinder(d=TUBE_OD, h=20);
        // fixing feet to the frame
        corner_holes(BASE_W, BASE_D, inset=6, h=BASE_T*2);
    }
}

assert_fits([BASE_W, BASE_D, SERVO_H*0.6]);
servo_valve_mount();

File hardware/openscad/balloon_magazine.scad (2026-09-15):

// SPDX-License-Identifier: CERN-OHL-P-2.0
// SPDX-FileCopyrightText: 2026 CLSOFTLAB / Dr. Lee Il-guk (이일국) and Fireflies contributors
//
// balloon_magazine.scad — holds a stack of empty (un-inflated) envelopes and feeds
// one at a time to the fill station. Empty micro-balloons are flat, so the magazine
// is a slotted comb the flat envelopes drop through, plus a gently sloped floor so
// the next one presents to the loader.

include <lib/common.scad>

MAG_W     = 90;    // X
MAG_D     = 70;    // Y (feed direction)
MAG_H     = 60;    // Z stack height
SLOT_W    = 3.0;   // width of each envelope slot
SLOT_N    = 12;    // number of slots (capacity guide)
FLOOR_SLOPE = 10;  // deg, so envelopes slide toward the exit

module balloon_magazine() {
    difference() {
        // outer shell, open top and open exit face (+Y)
        difference() {
            rounded_box([MAG_W, MAG_D, MAG_H], r=4);
            translate([WALL, WALL, WALL])
                rounded_box([MAG_W-2*WALL, MAG_D-2*WALL, MAG_H], r=2);
            // open the exit face
            translate([WALL*2, MAG_D-WALL-EPS, WALL*2])
                cube([MAG_W-4*WALL, WALL+2*EPS, MAG_H]);
        }
        // sloped floor to urge the stack forward
        translate([-EPS, -EPS, 0])
            rotate([FLOOR_SLOPE, 0, 0])
                cube([MAG_W+2*EPS, MAG_D+20, WALL]);
    }

    // comb of dividers that keep flat envelopes separated so they feed singly
    for (i = [1:SLOT_N])
        translate([MAG_W/2 - (SLOT_N/2)*(SLOT_W+1.2) + i*(SLOT_W+1.2), WALL, WALL])
            cube([1.2, MAG_D-2*WALL-6, MAG_H*0.5]);

    // feet with clearance holes to bolt to the frame grid
    for (x = [10, MAG_W-10], y = [10, MAG_D-16])
        translate([x, y, 0]) difference() {
            cylinder(d=10, h=WALL);
            vhole(M3_CLEAR, WALL, 0, 0);
        }
}

assert_fits([MAG_W, MAG_D, MAG_H]);
balloon_magazine();

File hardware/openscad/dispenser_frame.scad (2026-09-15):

// SPDX-License-Identifier: CERN-OHL-P-2.0
// SPDX-FileCopyrightText: 2026 CLSOFTLAB / Dr. Lee Il-guk (이일국) and Fireflies contributors
//
// dispenser_frame.scad — base plate + upright back panel for the desktop dispenser.
// The other modules (magazine, gate, valve mount, load-cell mount, LED jig, tray)
// bolt onto this. Prints as a flat base with a low back wall (fits the bed upright
// or laid down).

include <lib/common.scad>

FRAME_W   = 190;   // X footprint
FRAME_D   = 120;   // Y footprint
BASE_T    = 5;     // base plate thickness
BACK_H    = 140;   // upright back-panel height
BACK_T    = 5;     // back-panel thickness
RIB_T     = 4;     // gusset ribs

module dispenser_frame() {
    // base plate
    difference() {
        rounded_box([FRAME_W, FRAME_D, BASE_T], r=6);
        // mounting grid for modules (M3 clearance holes)
        for (x = [20:30:FRAME_W-20], y = [20:30:FRAME_D-20])
            vhole(M3_CLEAR, BASE_T, x, y);
        // helium-line pass-through near the back-left
        translate([28, FRAME_D-18, -EPS]) cylinder(d=10, h=BASE_T+2*EPS);
    }

    // upright back panel along the +Y edge
    translate([0, FRAME_D-BACK_T, 0])
    difference() {
        rounded_box([FRAME_W, BACK_T, BACK_H], r=4);
        // cable window
        translate([FRAME_W/2-25, -EPS, 40]) cube([50, BACK_T+2*EPS, 60]);
        // fixing holes for the electronics tray on the back panel
        for (x = [30, FRAME_W-30], z = [20, BACK_H-20])
            translate([x, BACK_T+EPS, z]) rotate([90,0,0]) cylinder(d=M3_TAP, h=BACK_T+2*EPS);
    }

    // two triangular gusset ribs so the tall panel does not fold over.
    // rotate([90,0,90]) maps the 2D triangle's local (x,y) onto world (Y,Z) with
    // thickness along +X; -40 in local-x runs the brace forward onto the base.
    for (x = [14, FRAME_W-14-RIB_T])
        translate([x, FRAME_D-BACK_T, BASE_T])
            rotate([90, 0, 90])
            linear_extrude(RIB_T)
                polygon([[0,0],[-40,0],[0,60]]);
}

assert_fits([FRAME_W, FRAME_D, BACK_H]);
dispenser_frame();

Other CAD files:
hardware/openscad/electronics_tray.scad
hardware/openscad/jellyfish_carrier.scad
hardware/openscad/led_test_jig.scad
hardware/openscad/load_cell_mount.scad
hardware/openscad/release_gate.scad

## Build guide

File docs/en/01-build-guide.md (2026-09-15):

# 01 · Build guide

> Part of Fireflies · CC BY 4.0 · © 2026 CLSOFTLAB, Dr. Lee Il-guk

This guide takes you from *watching* Fireflies in your browser to *running* a small indoor show.
Work in order — each step builds on the one before. The [design spec](00-design-spec.md) is the
single source of truth; if this guide and the spec ever disagree, the spec wins, so please
[open an issue](https://github.com/clsoftlab-lang/fireflies/issues).

> [!WARNING]
> Do not skip [03 · Safety & airspace](03-safety-and-airspace.md) and
> [04 · Leave no trace](04-leave-no-trace.md) before any real flight. The default, legal-anywhere
> mode is **indoor or tethered**. Free wind-release is advanced and permit-required.

## Contents

1. [Step 1 — Try the simulator](#step-1--try-the-simulator)
2. [Step 2 — Build one jellyfish unit](#step-2--build-one-jellyfish-unit)
3. [Step 3 — Build the dispenser](#step-3--build-the-dispenser)
4. [Step 4 — Run an indoor / tethered show](#step-4--run-an-indoortethered-show)
5. [Where the exact commands live](#where-the-exact-commands-live)

---

## Step 1 — Try the simulator

The simulator is the whole dream at full scale, and it needs no hardware. **Start here.**

- **Just open it:** double-click [`sim/index.html`](../../sim/index.html), or open it in any modern
  browser. There is no build step and no server.
- **On the web:** <https://clsoftlab-lang.github.io/fireflies/sim/>.

Play with the controls (number of units, wind strength, blink period, coupling strength, colour)
until the behaviour feels familiar: units drift on a gentle wind field, and their random flashes
pull into slow waves of unison. This is exactly what the hardware aims to reproduce, so it is the
best possible reference before you pick up a soldering iron.

**Run the simulator's tests** (Node.js 20+; the tests live under `sim/tests/`):

```bash
node --test sim/tests
```

This is the same command the [CI workflow](../../.github/workflows/ci.yml) runs on every change.

> The pulse-coupled sync model the simulator uses is explained, in plain words, in
> [05 · Synchrony explained](05-synchrony-explained.md). The firmware uses the identical model.

---

## Step 2 — Build one jellyfish unit

Goal: the smallest, lightest self-lit floater that drifts on indoor air. Build **one** and get it
blinking before you build many. The unit comes in two forms (design spec §3.1):

- **Firefly form** — a single blinking point of light.
- **Sky-jellyfish form (v1)** — the balloon is the *bell*, with 3–8 feather-light glowing
  **tendrils** hanging from it. Build the firefly form first; add tendrils once it flies and blinks.

Parts (see [02 · Bill of materials](02-bill-of-materials.md) for the full list and prices):

| Part | Choice | Why |
|---|---|---|
| Envelope (bell) | Metallised-film micro-bubble ~5–8 cm, **or** biodegradable latex micro-balloon | Foil holds helium longer; latex breaks down better. 2 cm is simulator-only. |
| Lift gas | Helium, trimmed to **near-neutral buoyancy** | It should hover and drift, not shoot up or sink. |
| Light | 1 × micro-LED, warm amber (~590 nm) + a **capacitor-boosted flash** | Amber matches fireflies; the capacitor gives the sharp, spark-like *pop* (spec §5.1) with **no spark**. |
| Power | Smallest coin/film cell inside the lift budget | Minutes to a couple of hours of runtime. |
| Blink circuit | ATtiny-class microcontroller, **or** a discrete analog blinker | Firmware enables synchrony; the analog option just blinks. |
| Sync sensor (optional) | 1 × phototransistor | Lets a unit see neighbours' flashes and fall into rhythm. |
| Tendrils (jellyfish form) | 3–8 light strands, a few micro-LEDs each | Must hang and sway softly; every milligram stays inside the free-lift budget. |

Build order for one unit:

1. **Assemble the LED payload:** micro-LED + capacitor-boosted flash driver + smallest cell +
   ATtiny-class blink circuit (+ optional phototransistor). Keep it feather-light.
2. **Flash the blink/sync firmware** and confirm the LED does the crisp capacitor *pop*, not a dim
   steady glow. Two to five units placed near each other should fall into sync by light alone.
3. **Fill and trim the bell:** add helium until the balloon **neither rises fast nor sinks** — it
   hovers. This trim is the make-or-break skill (spec F2). The buoyancy rule of thumb: helium lifts
   roughly **1 gram per litre** it displaces, so the payload mass sets the smallest balloon you can use.
4. **Attach the payload** below the bell so the unit is near-neutral overall.
5. **(Jellyfish form)** add 3–8 tendrils, each a light strand with a few micro-LEDs, so the light
   runs **down each tendril top→bottom in a slow wave**. Keep them light enough to sway, not stiff.

> [!NOTE]
> **The 2 cm thumbnail unit is simulator-only.** A real balloon that lifts even a micro-LED, a cell
> and a circuit is bigger. Build the smallest unit that actually floats, and be honest about it.

---

## Step 3 — Build the dispenser

The dispenser is one 3D-printable desktop machine that turns raw balloons + a helium source into
finished, glowing, neutrally-trimmed units and releases them on a button (design spec §4).

Reference parts: a Raspberry Pi Pico or Arduino-class controller, a micro servo/solenoid valve on
the helium line, a load cell + HX711-class amplifier for buoyancy, an LED-test photodiode, and a
3D-printed frame, magazine and release gate. Full BOM and wiring live in `hardware/`.

The five stages it automates:

1. **Load** an empty envelope from the magazine.
2. **Fill** with helium to a target free-lift, measured on the load cell, so the unit is **trimmed
   near neutral**. Firmware closes the valve at target.
3. **Attach & arm** the LED payload and run a **light self-test** (blink once) so no dead unit is
   released.
4. **Release** one unit at a time, or a gentle rhythm of them, on the operator's start signal.
5. **Start button / all-stop:** the start button is the *only* live control ("begin releasing"); it
   is also an all-stop, plus a documented plan for bringing tethered units down.

Print the parts, wire per `hardware/`, and flash the dispenser controller firmware from `firmware/`.
Bench-test the fill/trim/test/release cycle **with no LED payload and the valve closed** first, then
with one unit.

---

## Step 4 — Run an indoor / tethered show

This is the default, legal-anywhere mode, and the target of the whole reference design.

1. Read [03 · Safety & airspace](03-safety-and-airspace.md) and
   [04 · Leave no trace](04-leave-no-trace.md) in full.
2. Choose an **indoor** space, or **tether** each unit on a fine, retrievable line outdoors in still
   air. Ventilate: helium is an asphyxiant in enclosed spaces.
3. Trim each unit near-neutral, light-test it, and **log it**. The released count must equal the
   recovered count.
4. Release a gentle rhythm of units on the start button and watch them drift and sync.
5. **Recover every unit.** Reconcile your count. Leave the space as you found it.

Scale up gradually: one unit on the bench → 2–5 syncing by light → a tethered indoor show of 10–50
(design spec phases P1–P3). Free release (P4) is advanced, permit-required, biodegradable-only, with
full recovery.

---

## Where the exact commands live

This project is built by parallel tracks from the [design spec](00-design-spec.md). The exact,
authoritative commands for each component live in that component's own README as it is populated:

- **Simulator:** `sim/README.md` — run and test (`node --test sim/tests`).
- **Hardware (unit + dispenser):** `hardware/README.md` — parts, printing, wiring, buoyancy trim,
  helium handling. This is the **authoritative BOM**; [02 · Bill of materials](02-bill-of-materials.md)
  is a provisional summary until then.
- **Firmware:** `firmware/README.md` — flashing the blink/sync firmware and the dispenser controller.

If a component folder is not yet in your checkout, follow the design spec sections referenced above
and treat the hardware figures as provisional.
